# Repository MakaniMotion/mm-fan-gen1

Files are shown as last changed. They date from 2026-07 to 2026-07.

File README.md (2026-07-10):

<p align="center">
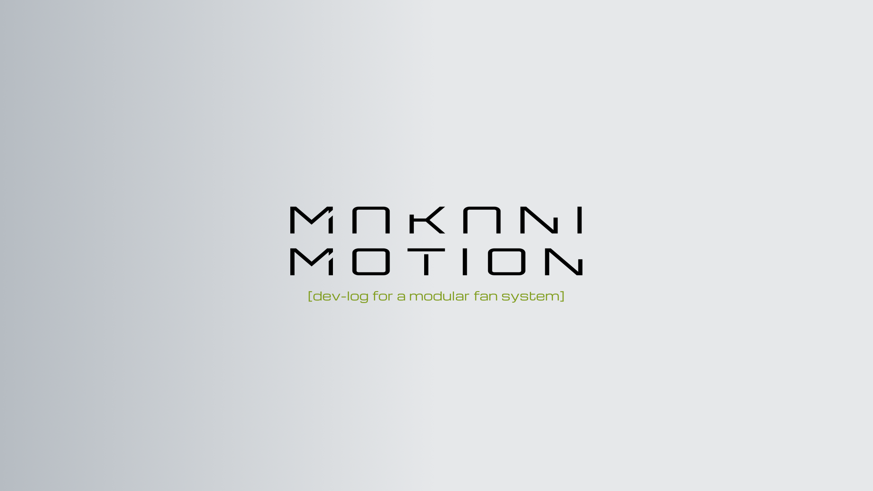
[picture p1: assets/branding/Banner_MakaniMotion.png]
MakaniMotion Banner
  
</p>

# MakaniMotion MM-Fan GEN 1

A modular DIY fan platform.

## Table of Contents

- [Overview](#overview)
- [Motivation](#motivation)
- [Modules](#modules)
  - [MM-BASE](#mm-base)
  - [MM-AIR](#mm-air)
  - [MM-TRI](#mm-tri)
- [System Parts](#system-parts)
- [Build Configurations](#build-configurations)
  - [Table Version](#table-version)
  - [Stand Version](#stand-version)
- [Project Status](#project-status)
- [License / Usage](#license--usage)

## Overview

MakaniMotion MM-Fan GEN 1 is a modular DIY fan platform built around interchangeable modules.

The system can be assembled in different configurations and combines PC fan hardware, 3D-printed mechanical parts and a simple control interface.

## Motivation

The goal of this project is to develop a fan system that is quiet, modular, energy-efficient and visually aesthetic.

The design is based on high-performance PC / gaming fans. These fans are developed in a highly competitive market and are therefore typically optimized for low noise, low power consumption and high airflow.

The main challenge of MakaniMotion MM-Fan GEN 1 is to adapt these properties to the use case of a room fan. Instead of only moving air through a PC case, radiator or filter, the system is designed to create a more focused and usable airflow for indoor use.

## Modules

MakaniMotion MM-Fan GEN 1 is built around three main modules. Each module has a dedicated function and can be combined with the other modules depending on the desired build configuration.

### MM-BASE

<p align="left">
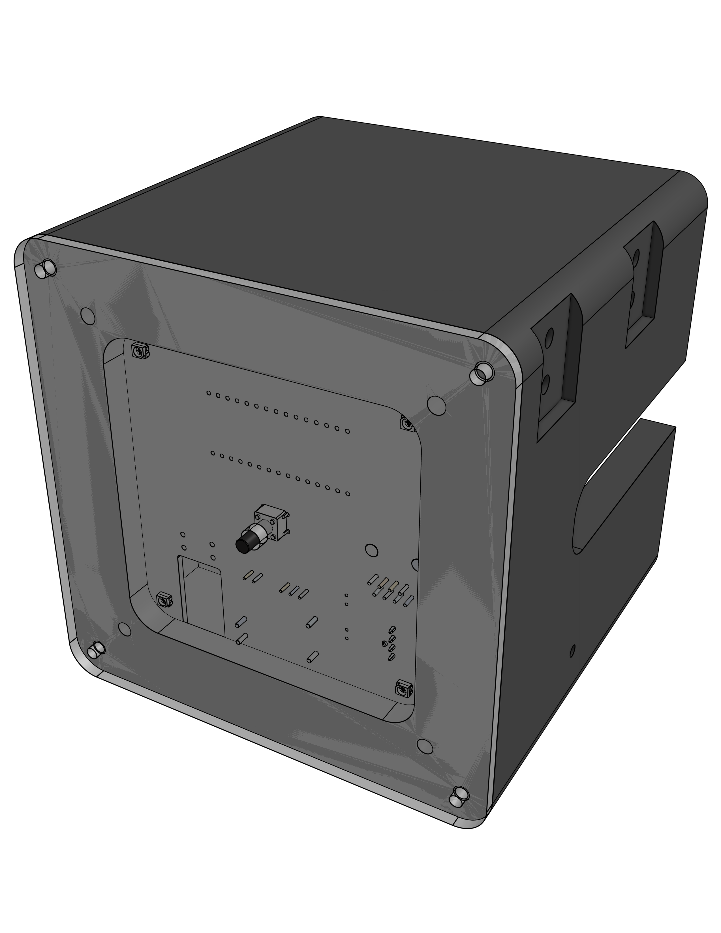
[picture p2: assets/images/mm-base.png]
MM-BASE Module
  
</p>

**MM-BASE** is the base and control module of the system.

It provides the main electrical control interface, power distribution and user interface for the fan setup. The GEN 1 main PCBA uses an Arduino Nano to keep the project easy to reproduce.

MM-BASE is intended to be powered from a suitable 5 V USB power bank. The enclosure is designed to fit smaller power banks inside the module, allowing the system to be used as a battery-powered device without using a custom battery pack.

In the current GEN 1 prototype, MM-BASE may not work directly with all USB chargers. A power source with an active/default 5 V output is required.

| Item | Description |
|---|---|
| Module name | MM-BASE |
| Main PCBA | mm-main-pcba-gen1-reva |
| Controller | Arduino Nano |
| Power input | 5 V |
| Recommended power source | Suitable USB power bank |
| Power source requirement | Active/default 5 V output |
| Power bank integration | Enclosure space for smaller power banks |
| Power stage | 10 W DC/DC converter |
| Supported MM-AIR modules | Up to 5 MM-AIR modules in the current setup |
| HMI | One push button for PWM level selection |
| Status indication | Four RGB LEDs indicate the selected PWM level using different colors |
| Design goal | Easy to build, easy to understand and suitable for DIY reproduction |

### MM-AIR

<p align="left">
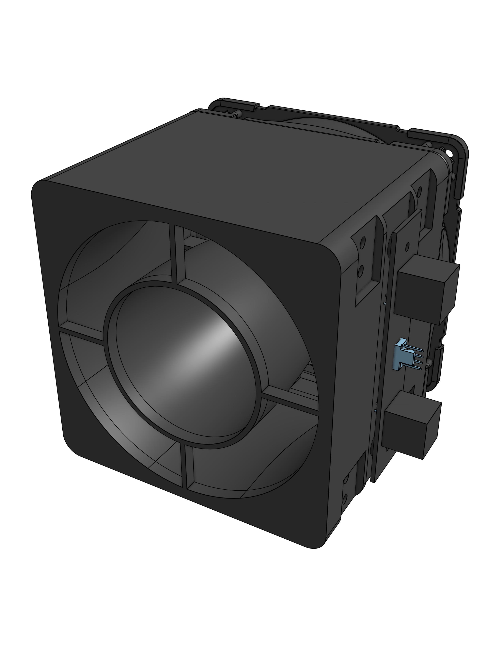
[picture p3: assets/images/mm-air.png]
MM-AIR Module
  
</p>

**MM-AIR** is the fan / airflow module of the system.

It uses a Noctua NF-A12x25 PWM 120 mm fan, selected for its low noise level, low power consumption and high airflow performance.

The fan is mounted to a 3D-printed shroud that reduces the outlet cross-section. This helps increase air velocity and creates a more focused airflow for use as a room fan.

An interface PCB is mounted on the side of the module. The **mm-interface-pcba-gen1-reva** connects MM-AIR to the daisy-chain system and provides two RJ45 sockets and one PC fan header.

| Item | Description |
|---|---|
| Module name | MM-AIR |
| Fan | Noctua NF-A12x25 PWM |
| Fan size | 120 mm |
| Fan control | PWM |
| Interface PCBA | mm-interface-pcba-gen1-reva |
| System connectors | 2 × RJ45 sockets for daisy-chain connection |
| Fan connector | 1 × PC fan header |
| Mechanical design | 3D-printed shroud |
| Airflow concept | Reduced outlet cross-section to increase air velocity |
| Design goal | Quiet operation with focused, usable airflow |

### MM-TRI

<p align="left">
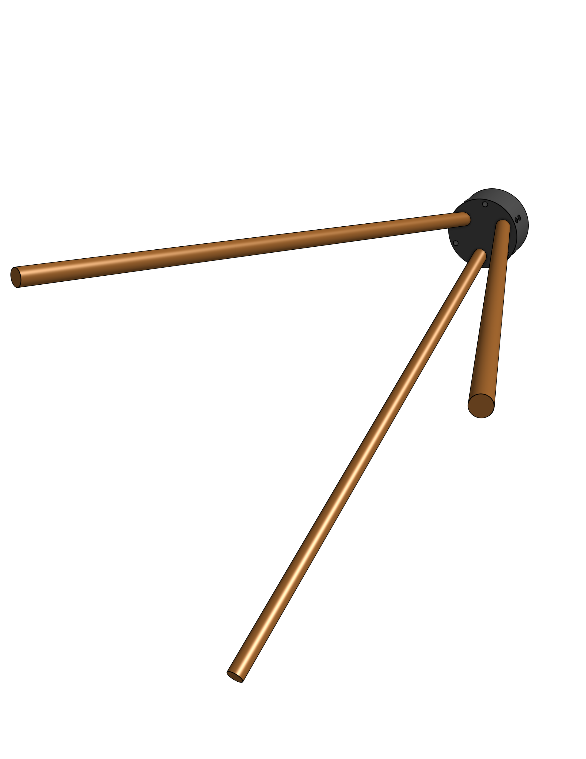
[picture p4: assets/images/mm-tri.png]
MM-TRI Module
  
</p>

**MM-TRI** is the tripod module for the free-standing build configuration.

It provides a simple and stable three-leg support structure for the system.

The three-leg design avoids mechanical overconstraint and helps the fan stand securely on uneven surfaces.

The module is intentionally kept simple and minimal while still maintaining an elegant appearance. In the current version, MM-TRI is attached to MM-BASE using three screws, making it easy to switch between the table version and the free-standing configuration.

| Item | Description |
|---|---|
| Module name | MM-TRI |
| Module type | Tripod module |
| Mechanical concept | Three-leg support structure to avoid mechanical overconstraint |
| Mounting interface | Attached to MM-BASE using a single screw |
| Required for | Stand version |
| Design goal | Simple, stable and elegant free-standing support |

## System Parts

The system also includes physical parts that belong to the overall GEN 1 system but are not assigned to a single module.

- **MM-CONNECT** – mechanical connection element
- **Connection Cables** – The connection cables are based on RJ45, but they are not used for Ethernet networking. They are repurposed as system connection cables for power and signals between modules.

## Build Configurations

MakaniMotion MM-Fan GEN 1 can typically be assembled in two main configurations:

### Table Version

The table version is designed to be placed on a desk or similar surface.

<p align="left">
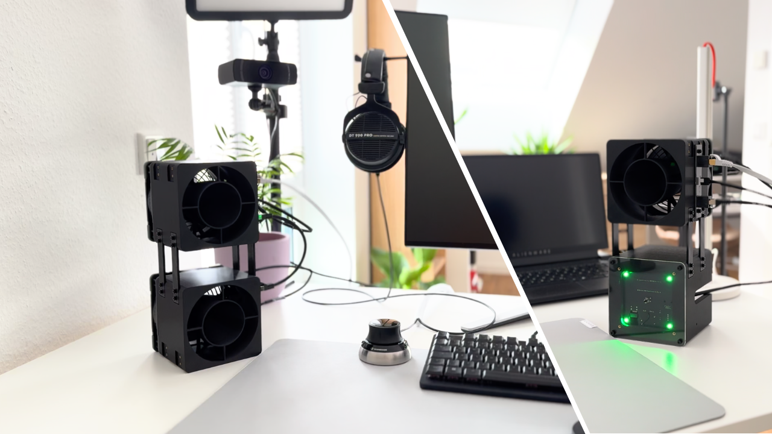
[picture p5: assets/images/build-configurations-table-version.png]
MakaniMotion Fan GEN 1 Table Version
  
</p>

In this configuration, the **MM-TRI** tripod module is not required.

Because the modules are connected by cables, the physical layout can be adapted to different use cases and desk setups.

### Stand Version

The stand version is designed as a free-standing fan setup.

<p align="left">
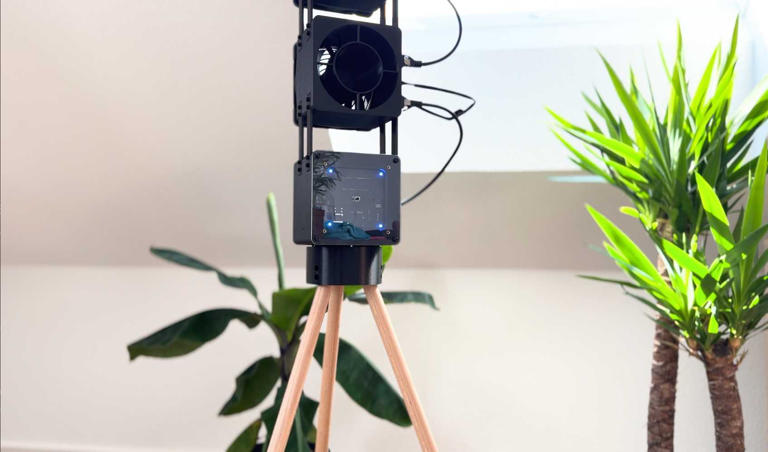
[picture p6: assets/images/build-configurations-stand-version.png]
MakaniMotion Fan GEN 1 Stand Version
  
</p>

In this configuration, the **MM-TRI** tripod module is required.

## Project Status

Prototype / work in progress.

This repository contains the first product generation:

```text
MakaniMotion MM-Fan GEN 1
```

Module revisions within this generation are tracked separately, for example:

```text
MM-Base GEN 1 Rev A
MM-Air GEN 1 Rev A
MM-TRI GEN 1 Rev A
```

This project is a DIY development project and is not a certified consumer product.

No CE declaration, conformity assessment or safety certification.

Anyone building hardware based on this project does so at their own risk and is responsible for safe assembly and operation.

## License / Usage

This project is source-available for private and non-commercial use only.

Private individuals may view, download, build and modify the project files for personal use.

Non-commercial sharing or uploading of modified project files is allowed if MakaniMotion is clearly credited as the original source and this license remains included.

Commercial use is not permitted. This includes use by companies, commercial organizations, paid services, commercial product development, manufacturing for commercial purposes, or distributing physical devices, kits, parts or assemblies based on this project.

For details, see [`LICENSE.md`](LICENSE.md).

© MakaniMotion. All rights reserved unless otherwise stated.

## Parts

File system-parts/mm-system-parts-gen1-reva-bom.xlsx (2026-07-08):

MakaniMotion MM-SYSTEM-PARTS
Project | MakaniMotion MM-Fan GEN 1
Module | MM-SYSTEM-PARTS
Revision | Rev A
Item | Component | Sub component | Description | Qty | Source | Supplier / Manufacturer | Part No. / File Ref. | Link
1 | Network Cable S/FTP PIMF Cat 7 0.25 m Black Patch Cable Gigabit Ethernet LAN DSL CAT7 Cable |  | A cable is required for each MM-AIR module used | dependet | Buy |  |  | https://www.amazon.de/gp/product/B08HDJLJ9J/ref=ox_sc_act_title_1?th=1&language=en_GB
2 | Network Cable S/FTP PIMF Cat 7 0.50 m Black Patch Cable Gigabit Ethernet LAN DSL CAT7 Cable |  | A slightly longer cable is required for the connection from MM-BASE to MM-AIR. | 1 | Buy |  |  | https://www.amazon.de/gp/product/B08HDG8GV2/ref=ox_sc_act_title_1?th=1&language=en_GB
3 | Screw M3 x 8mm |  | 16 Screws are required for each MM-AIR module used | dependet | Buy
4 | M3 Washers |  | 16 Washers are required for each MM-AIR module used | dependet | Buy
5 | mm-connect-gen1-reva.stl |  | 4 are required for each MM-AIR module used | dependet | print

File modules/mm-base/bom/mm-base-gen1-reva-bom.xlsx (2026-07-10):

MakaniMotion MM-BASE
Project | MakaniMotion MM-Fan GEN 1
Module | MM-BASE
Revision | Rev A
Item | Component | Sub component | Description | Qty | Source | Supplier / Manufacturer | Part No. / File Ref. | Link
1 | mm-main-pcba-gen1-reva |  |  | 1 | KiCad
1001 |  | PCB | Gerber Files | 1 | Buy
1002 |  | DC/DC Converters - Through Hole 5Vin 5Vout 0-400mA 2W SIP Unreg Iso |  | 1 | Buy | MEAN WELL | SPUN02L-05 | https://www.mouser.de/ProductDetail/MEAN-WELL/SPUN02L-05
1003 |  | DC/DC Converters - Through Hole 4.7-9Vin 12Vout 833mA DIP Iso Reg |  | 1 | Buy | MEAN WELL | SKM10E-12 | https://www.mouser.de/ProductDetail/MEAN-WELL/SKM10E-12
1004 |  | Multi-Colour LEDs WL-SFTW SMT full-color TOP LED waterclear |  | 4 | Buy | Wurth Elektronik | 150141M173100 | https://www.mouser.de/ProductDetail/Wurth-Elektronik/150141M173100?qs=2kOmHSv6VfT%2Fmnpysgc7Ng%3D%3D
1005 |  | Short-stroke key 6x6 mm, height: 12.5 mm, 12 V, vert. |  | 1 | Buy | FREI | JTP-1130D | https://www.reichelt.com/de/en/shop/product/short-stroke_key_6x6_mm_height_12_5_mm_12_v_vert_-27894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
1006 |  | Arduino Nano |  | 1 | Buy | Arduino | A000005 | https://store.arduino.cc/products/arduino-nano
1007 |  | Aluminium Electrolytic Capacitors - Radial Leaded WCAP-ATG8 100uF 35V 20% Radial |  | 2 | Buy | Wurth Elektronik | 860010573007 | https://www.mouser.de/ProductDetail/Wurth-Elektronik/860010573007
1008 |  | Bipolar Transistors - BJT LO V NPN TRANSISTOR 40V 4.0A |  | 6 | Buy | onsemi | NSS40201LT1G | https://www.mouser.de/ProductDetail/onsemi/NSS40201LT1G?qs=JZRcihQa5buDxAwNVotiBw%3D%3D
1009 |  | USB Connectors USB Type C Receptacle Surface Mount Single Row 6Pin |  | 1 | Buy | Amphenol FCI | 10164359-00011LF | https://www.mouser.de/ProductDetail/Amphenol-FCI/10164359-00011LF?qs=MyNHzdoqoQLpQ%2FmSqA1%252BtQ%3D%3D
1010 |  | Modular Connectors / Ethernet Connectors WR-MJ_8P8C_THT_Vertical |  | 1 | Buy | Wurth Elektronik | 615008160321 | https://www.mouser.de/ProductDetail/Wurth-Elektronik/615008160321?qs=OlC7AqGiEDmnhkTBXznxsQ%3D%3D
1011 |  | female connector 2,54mm, 1x16, separable, gold plated |  | 2 | Buy | FISCHER ELEKTRONIK | BL1.16 G | https://www.reichelt.com/de/en/shop/product/female_connector_2_54mm_1x16_separable_gold_plated-283786
1012 |  | Resistor 3KOhm 1206 |  | 3 | Buy
1013 |  | Resistor 90Ohm 1206 |  | 8 | Buy
1014 |  | Resistor 150Ohm 1206 |  | 4 | Buy
2 | mm-base-gen1-enclosure-cover-reva.step |  |  | 1 | Buy or print
3 | M3 x 8mm |  | mm-base-gen1-enclosure-cover-reva.step mounting | 4 | Buy
4 | M3 Washers |  | mm-base-gen1-enclosure-cover-reva.step mounting | 4 | Buy
5 | M3 x 6mm |  | PCB mounting | 4 | Buy
6 | M3 thread insert |  |  | 22 | Buy | ruthex | GE-M3x57-001 | https://www.ruthex.de/en/products/ruthex-gewindeeinsatz-m3-100-stuck-rx-m3x5-7-messing-gewindebuchsen
7 | mm-base-gen1-enclosure-reva.stl |  |  | 1 | print
8 | USB C 180 Degree Angled Adapter |  | Depending on the USB connector, this adapter is necessary | 1 | buy |  |  | https://www.amazon.de/-/en/dp/B0BLMTGX8H?ref_=ppx_hzsearch_conn_dt_b_fed_asin_title_8&th=1
9 | USB C Cable 0.5m |  | Short cable for connecting a power bank | 1 | buy

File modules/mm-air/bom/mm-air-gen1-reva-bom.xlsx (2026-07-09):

MakaniMotion MM-AIR
Project | MakaniMotion MM-Fan GEN 1
Module | MM-AIR
Revision | Rev A
Item | Component | Sub component | Description | Qty | Source | Supplier / Manufacturer | Part No. / File Ref. | Link
1 | mm-interface-pcba-gen1-reva |  |  | 1 | KiCad
1001 |  | PCB | Gerber Files | 1 | Buy
1002 |  | Modular Connectors / Ethernet Connectors WR-MJ_8P8C_THT_Vertical |  | 2 | Buy | Wurth Elektronik | 615008160321 | https://www.mouser.de/ProductDetail/Wurth-Elektronik/615008160321?qs=OlC7AqGiEDmnhkTBXznxsQ%3D%3D
1003 |  | Headers & Wire Housings 4P VERT HDR W/FL |  | 1 | Buy | Molex | 47053-1000 | https://www.mouser.de/ProductDetail/Molex/47053-1000?qs=ph4zPCVRuvqoDX7hrEhxNA%3D%3D
2 | M3 thread insert |  |  | 20 | Buy | ruthex | GE-M3x57-001 | https://www.ruthex.de/en/products/ruthex-gewindeeinsatz-m3-100-stuck-rx-m3x5-7-messing-gewindebuchsen
3 | Screw M3 x 30mm |  | Fan mounting | 4 | Buy
4 | Screw M3 x 6mm |  | mm-interface-pcba-gen1-reva mounting | 2 | Buy
5 | M3 Washers |  | Mounting Hardware | 4 | Buy
6 | NF-A12x25 PWM chromax.black.swap |  | Fan | 1 | Buy | Noctua | NF-A12x25 PWM chromax.black.swap
7 | NA-FG1-12 Sx2 |  | Fan grills | 1 | Buy | Noctua | NA-FG1-12 Sx2
8 | mm-air-shroud-gen1-reva |  |  | 1 | Print

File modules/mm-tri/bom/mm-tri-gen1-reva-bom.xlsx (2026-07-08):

MakaniMotion MM-TRI
Project | MakaniMotion MM-Fan GEN 1
Module | MM-TRI
Revision | Rev A
Item | Component | Sub component | Description | Qty | Source | Supplier / Manufacturer | Part No. / File Ref. | Link
1 | mm-tri-gen1-enclosure-reva.stl |  |  | 1 | print
2 | mm-tri-gen1-leg-reva.step |  | 20mm x 750mm | 3 | buy
3 | M3 x 8mm |  | MM-BASE Mounting | 3 | buy
4 | M3 Washers |  | MM-BASE Mounting | 3 | buy
5 | 3 × 10 mm wood screw |  | mm-tri-gen1-leg-reva Mounting | 3 | buy

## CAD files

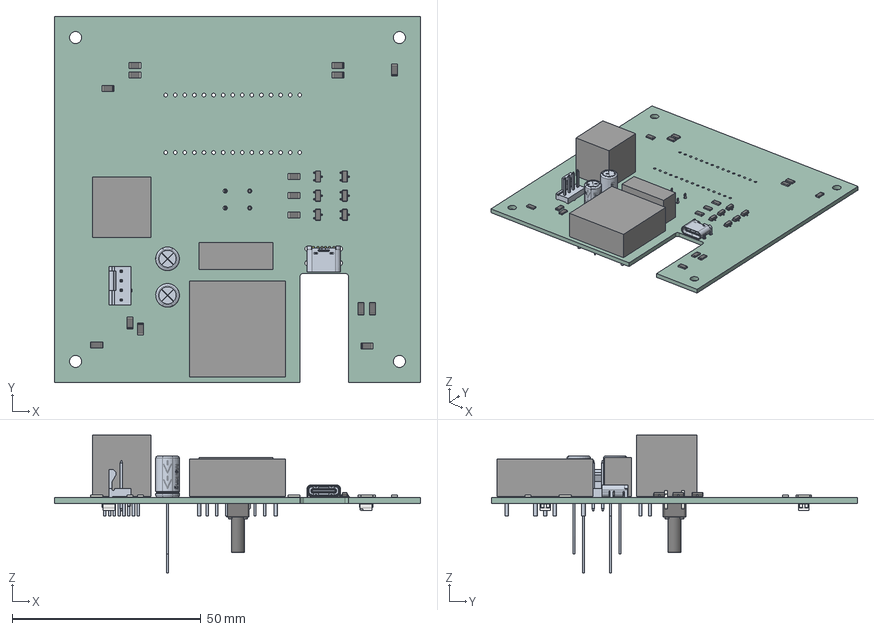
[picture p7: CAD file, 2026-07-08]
modules/mm-base/electronics/mm-main-pcba-gen1-reva/exports/mm-main-pcba-gen1-reva.step
97.0 x 97.0 x 36.5 mm
R_1206_3216Metric x 15
10164359-00011LF
ASSEMBLY x 3
SOT-23-3 x 6
CP_Wurth_WCAP-ATG8-P2.5D6.3L11 x 2
150141M173100 x 4
SW_PUSH_6mm_h13mm
DIYFAN_V1_PCB

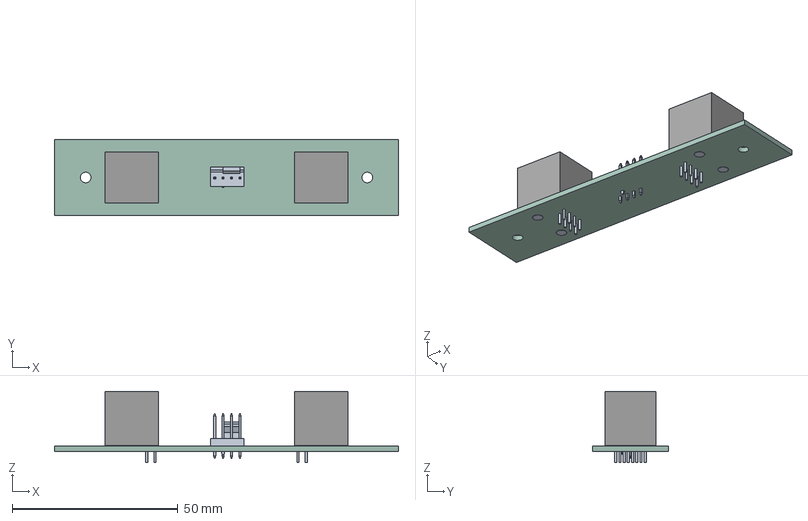
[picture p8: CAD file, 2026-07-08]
modules/mm-air/electronics/mm-interface-pcba-gen1-reva/exports/mm-interface-pcba-gen1-reva.step
103.9 x 22.9 x 21.4 mm
ASSEMBLY x 2
DIYFAN _interface_V1_PCB

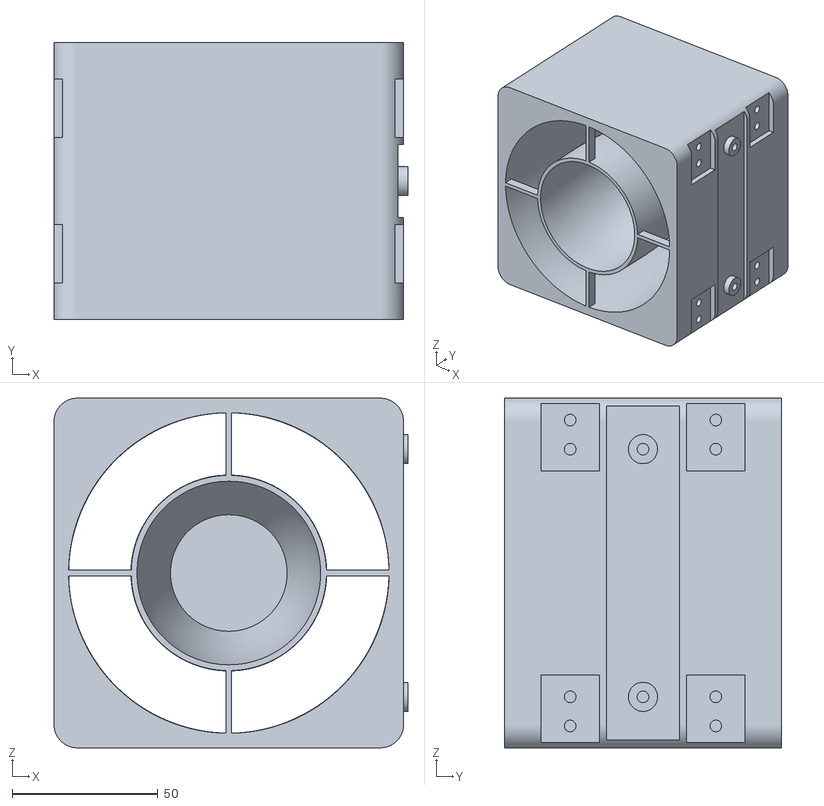
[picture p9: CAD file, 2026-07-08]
modules/mm-air/mechanical/mm-air-shroud-gen1-reva.stl
121.5 x 95.0 x 120.0

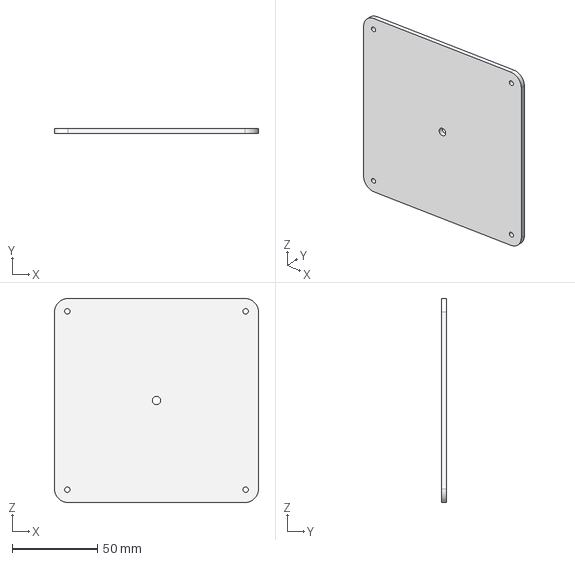
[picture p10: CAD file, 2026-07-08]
modules/mm-base/mechanical/mm-base-gen1-enclosure-cover-reva.step
120.0 x 3.00 x 120.0 mm

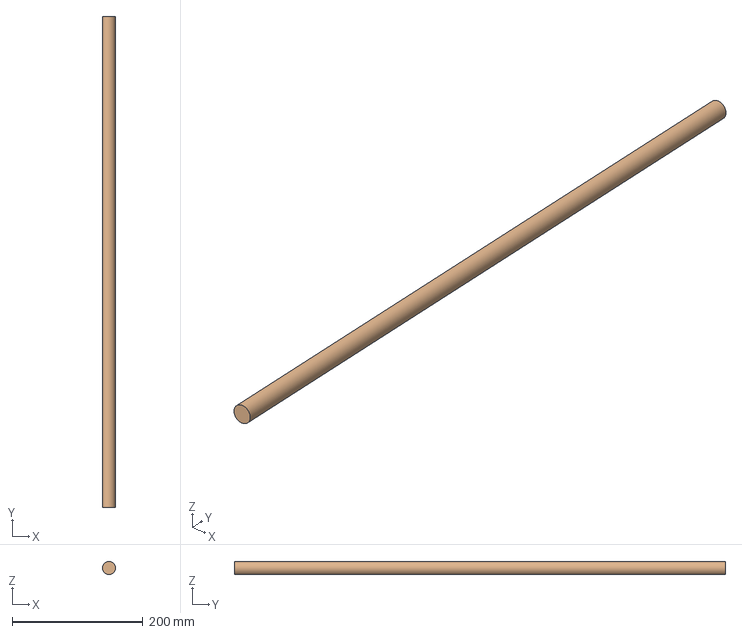
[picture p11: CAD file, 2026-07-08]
modules/mm-tri/mechanical/mm-tri-gen1-leg-reva.step
20.0 x 750.0 x 20.0 mm

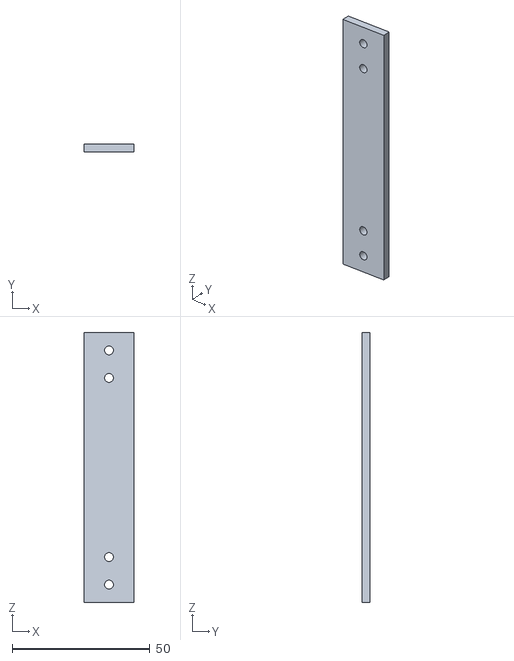
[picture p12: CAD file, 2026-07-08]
system-parts/mm-connect/mm-connect-gen1-reva.stl
18.0 x 3.00 x 98.0

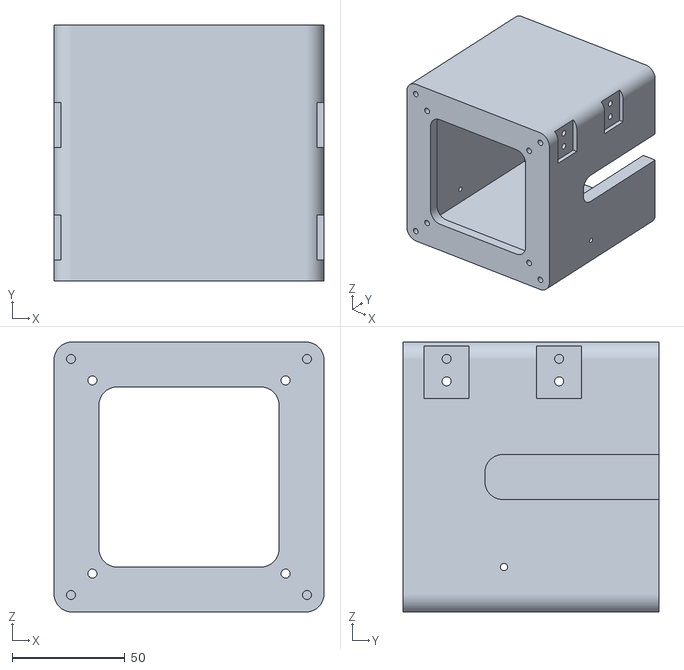
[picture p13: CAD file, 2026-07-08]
modules/mm-base/mechanical/mm-base-gen1-enclosure-reva.stl
120.0 x 114.0 x 120.0

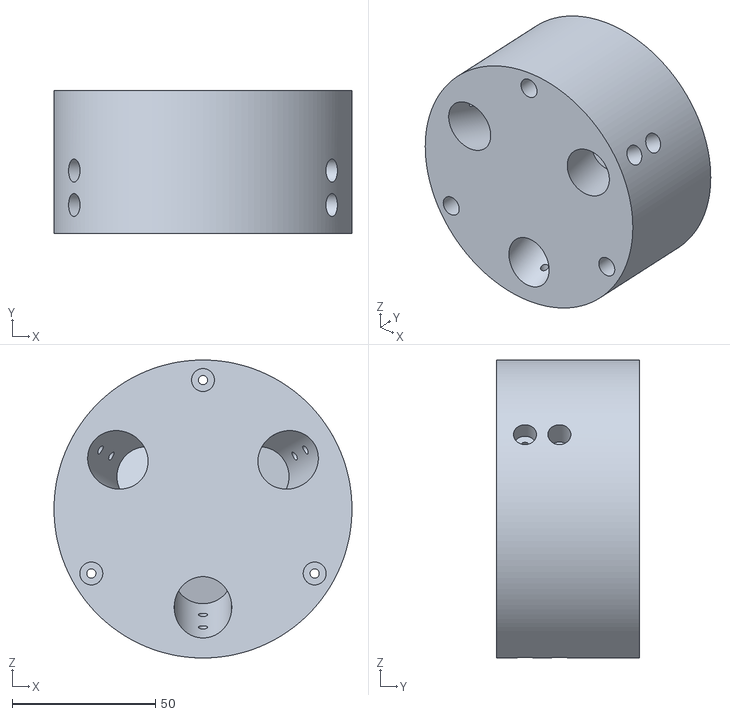
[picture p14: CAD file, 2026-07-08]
modules/mm-tri/mechanical/mm-tri-gen1-enclosure-reva.stl
104.0 x 50.0 x 104.0

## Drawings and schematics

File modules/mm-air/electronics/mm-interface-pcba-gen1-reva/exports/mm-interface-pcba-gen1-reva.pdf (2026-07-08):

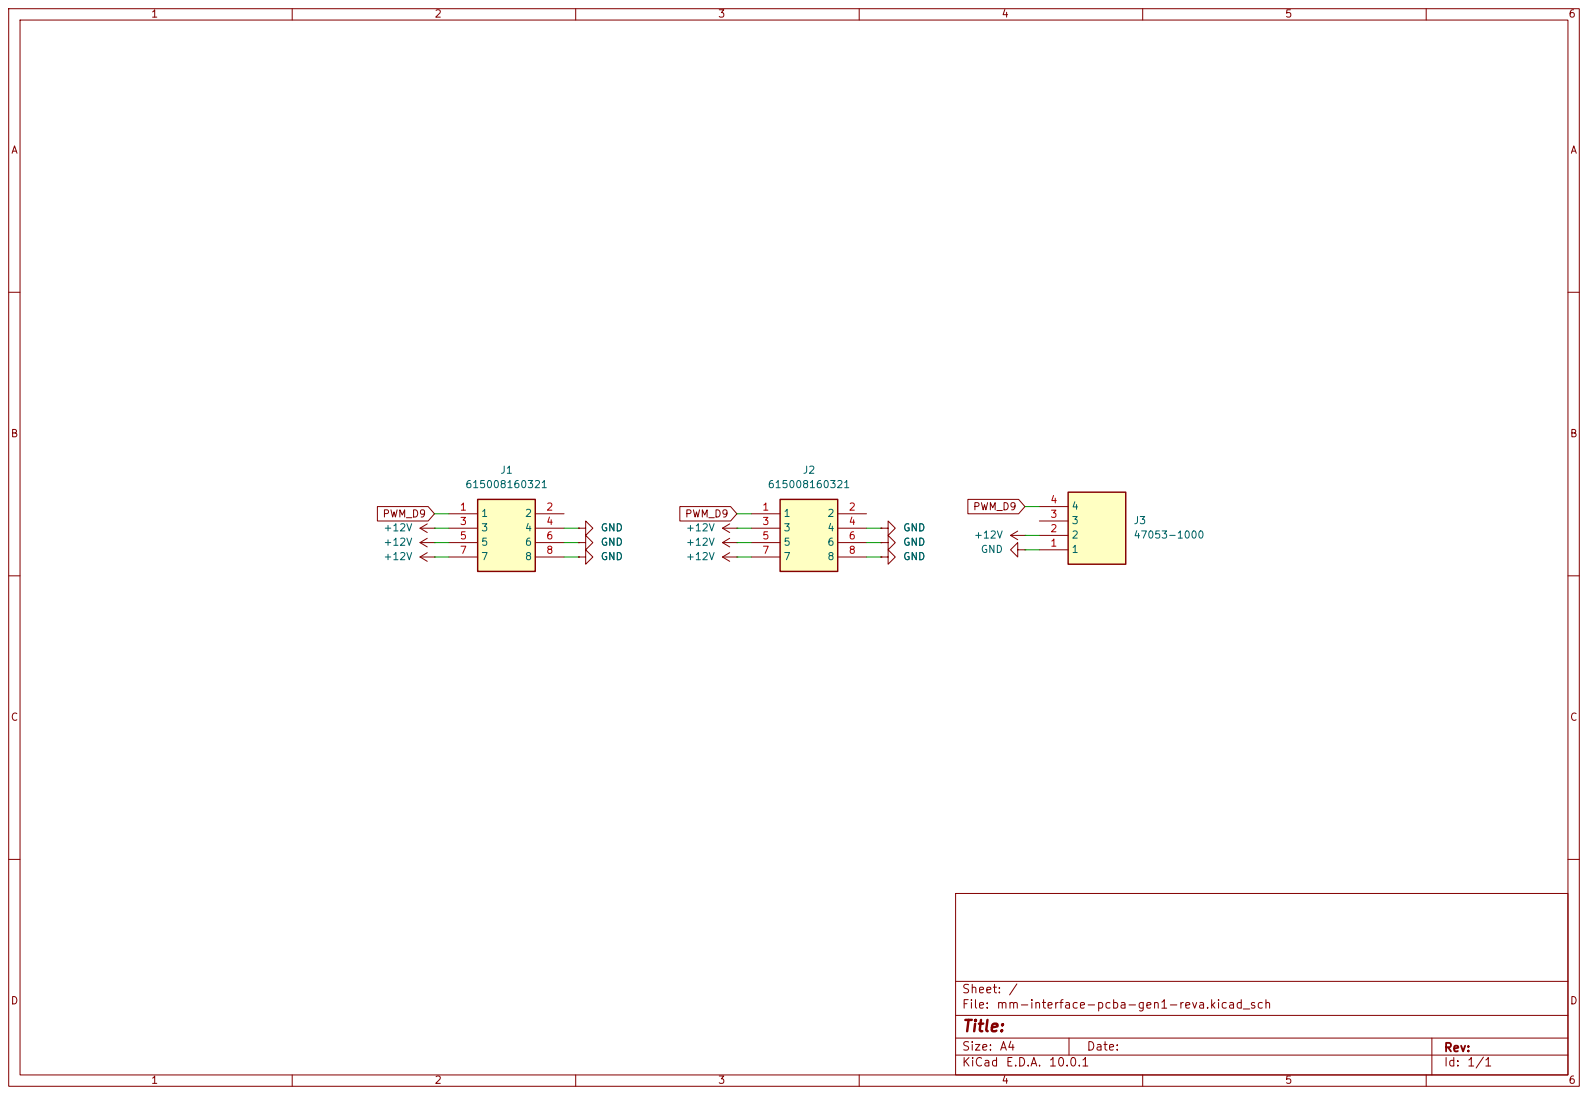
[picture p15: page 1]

File: mm-interface-pcba-gen1-reva.kicad_sch
Title:

Size: A4 | Rev:
KiCad E.D.A. 10.0.1 | Id: 1/1

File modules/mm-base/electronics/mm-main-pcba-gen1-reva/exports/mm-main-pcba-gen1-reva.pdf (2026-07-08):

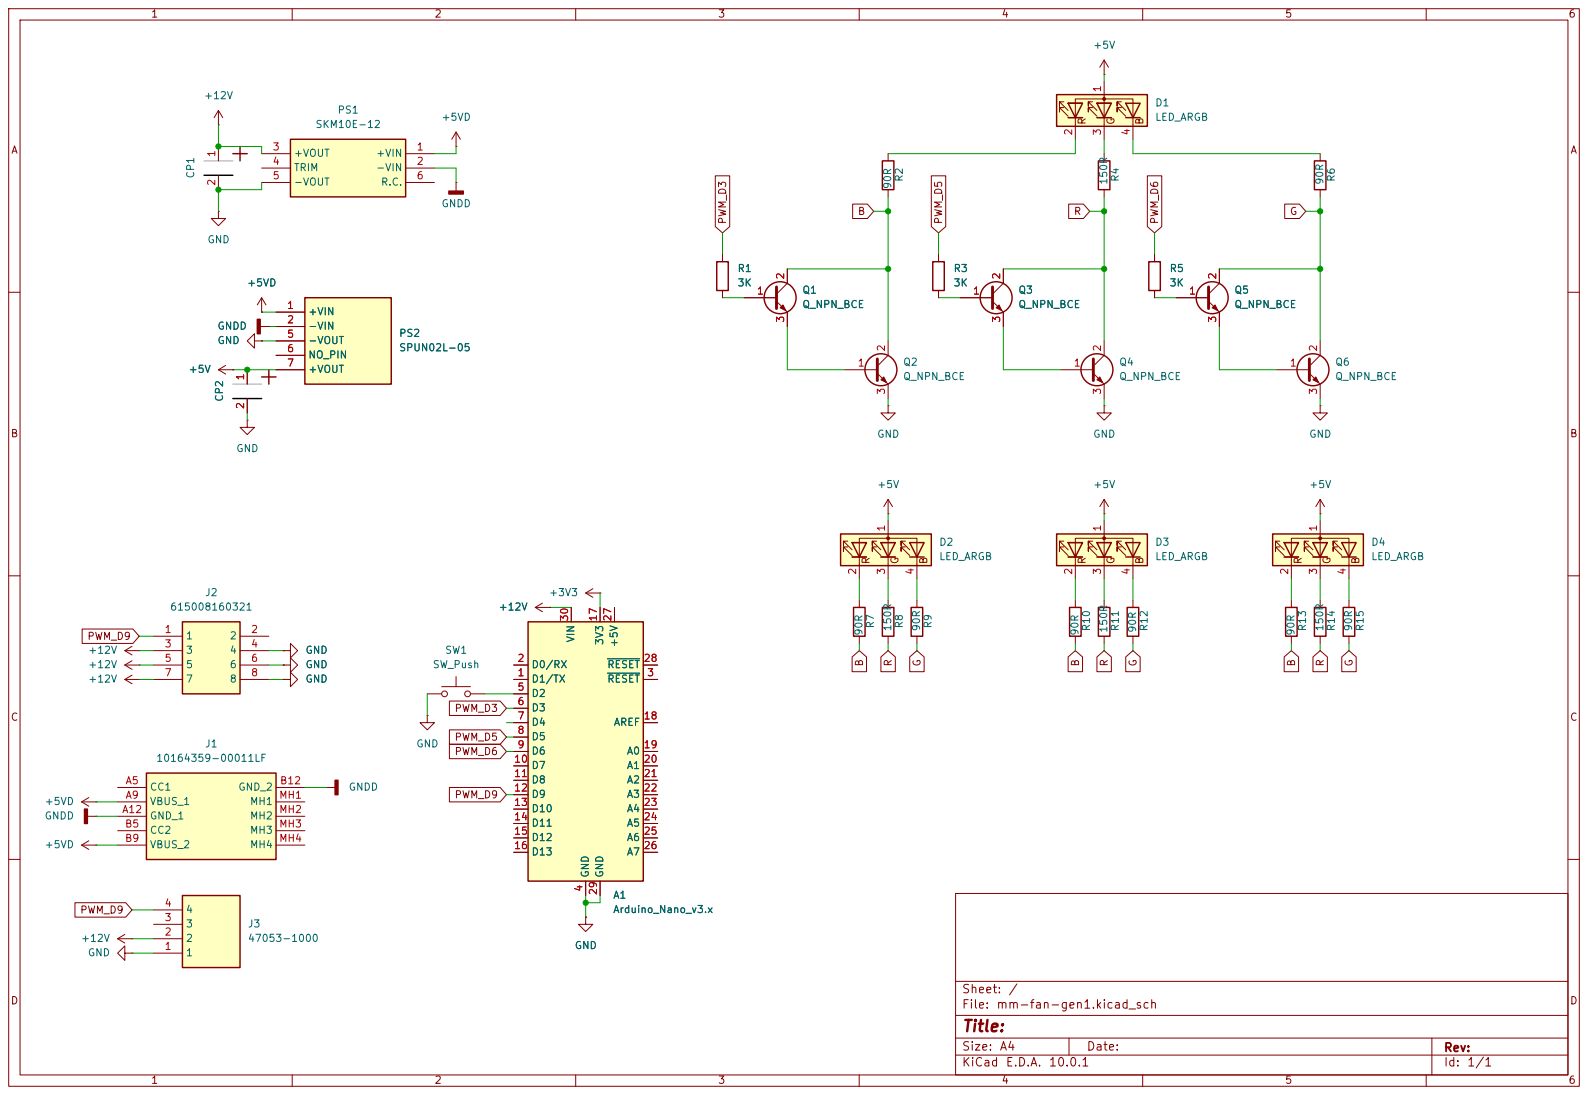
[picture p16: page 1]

Size: A4 | Rev:
KiCad E.D.A. 10.0.1 | Id: 1/1

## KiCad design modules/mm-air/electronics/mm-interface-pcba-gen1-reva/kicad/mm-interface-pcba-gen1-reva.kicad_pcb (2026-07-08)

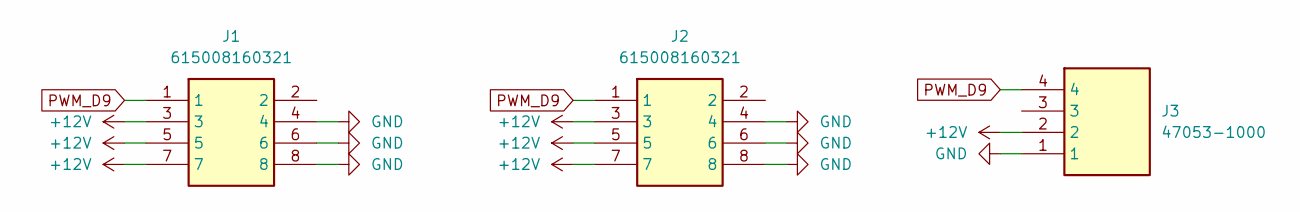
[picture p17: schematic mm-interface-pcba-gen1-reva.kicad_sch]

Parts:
J1, J2: 615008160321; Mouser Part Number 710-615008160321
J3: 47053-1000; 470531000; Mouser Part Number 538-47053-1000

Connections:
+12V: J1.3, J1.5, J1.7, J2.3, J2.5, J2.7, J3.2
GND: J1.4, J1.6, J1.8, J2.4, J2.6, J2.8, J3.1
PWM_D9: J1.1, J2.1, J3.4

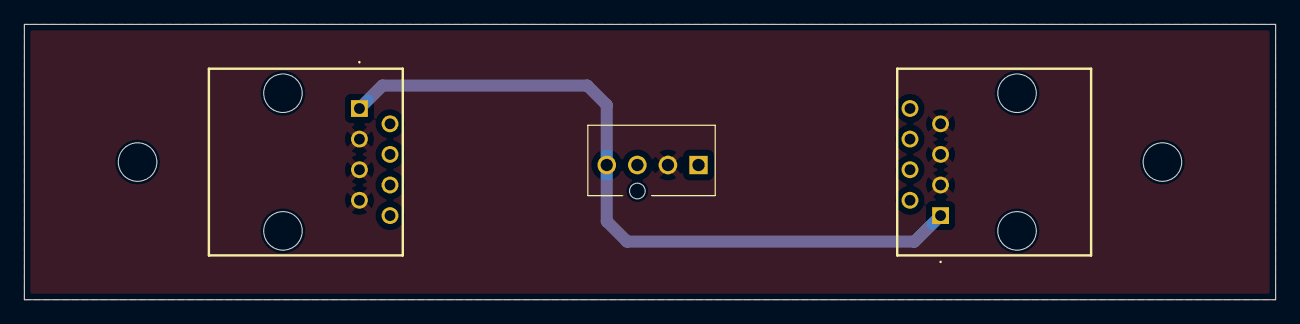
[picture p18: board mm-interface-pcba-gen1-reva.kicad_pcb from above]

Board: 2 copper layers, 103.9 x 22.9 mm, 3 parts (0 on the bottom side), 3 nets.

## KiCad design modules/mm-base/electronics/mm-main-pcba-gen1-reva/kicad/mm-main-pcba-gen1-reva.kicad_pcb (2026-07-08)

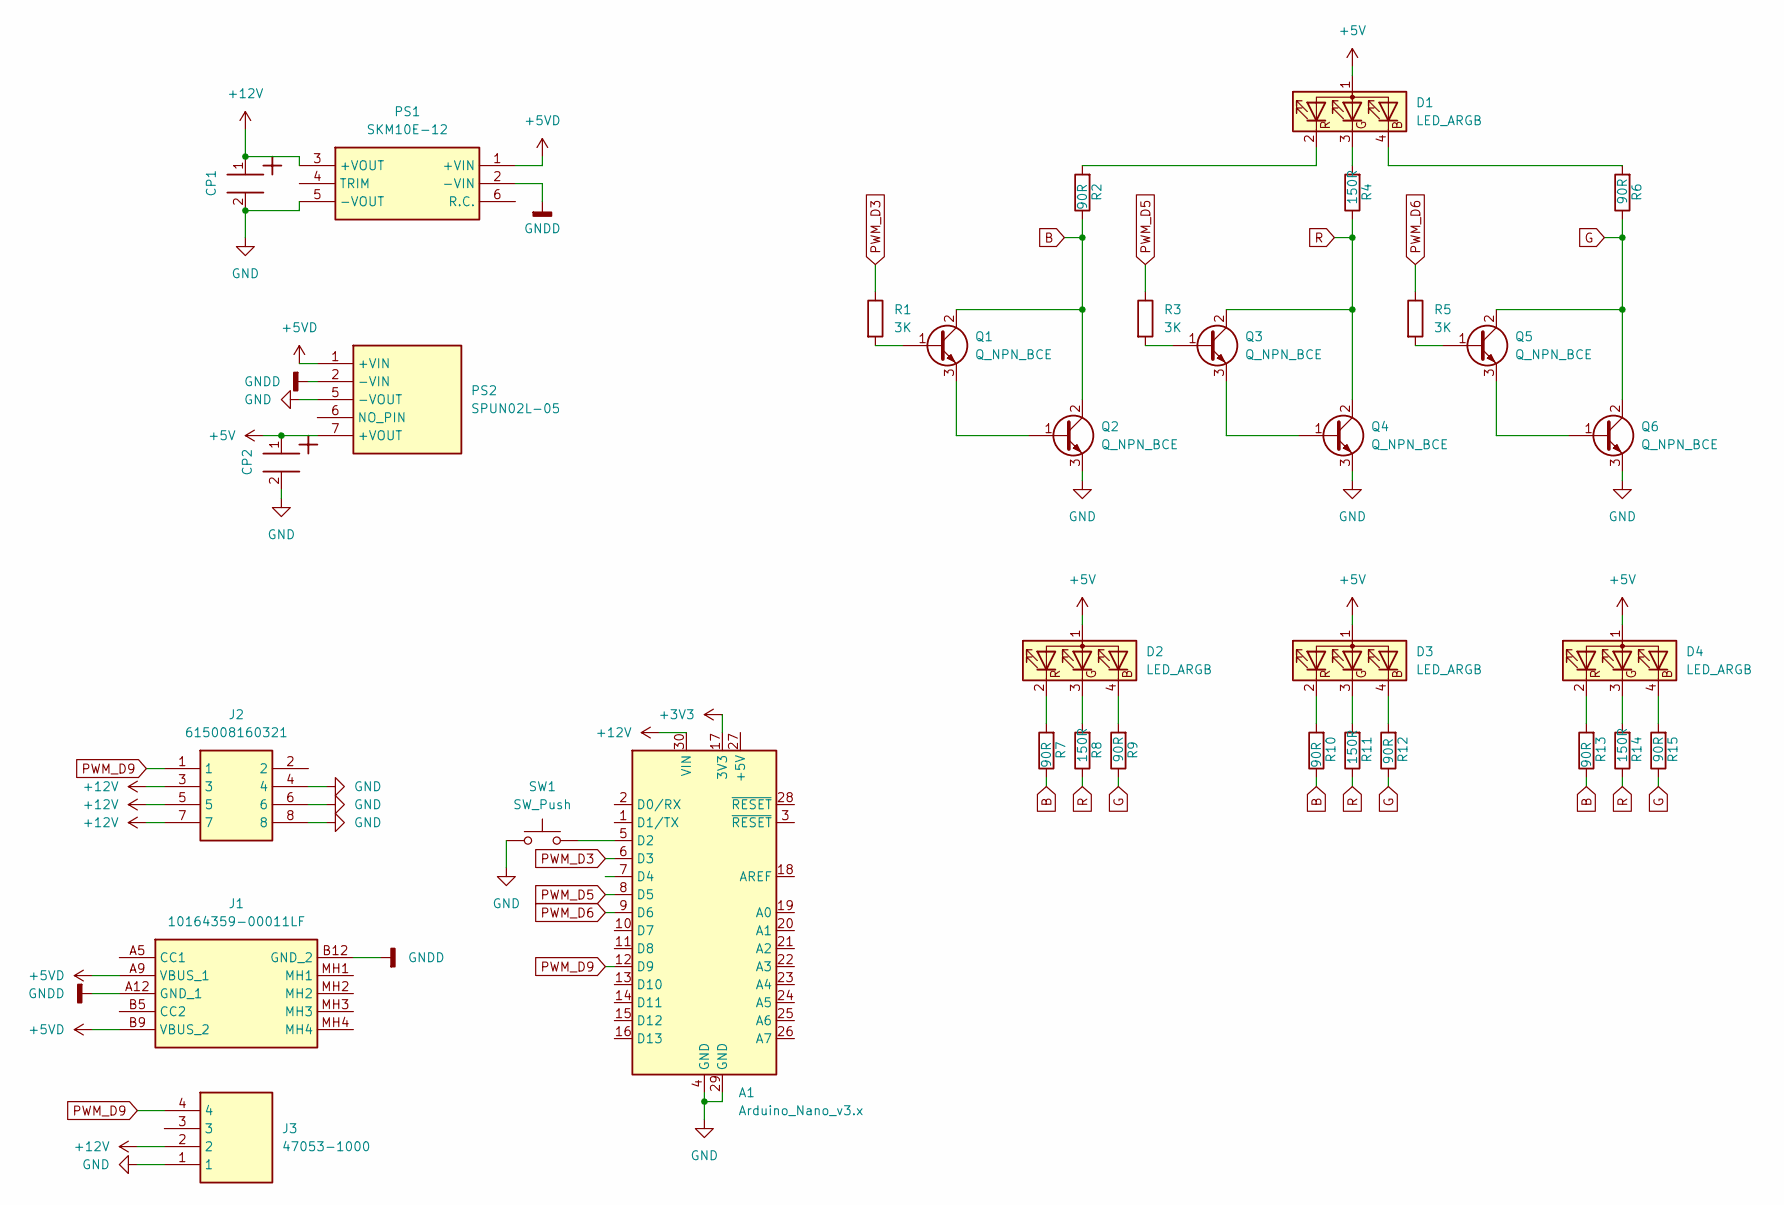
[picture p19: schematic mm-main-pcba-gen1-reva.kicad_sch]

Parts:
A1: Arduino_Nano_v3.x; Arduino_Nano
CP1, CP2: P2.5D6.3L11_860010573007_Modified; CP_Wurth_WCAP-ATG8-P2.5D6.3L11; Part Number 860010573007
D1, D2, D3, D4: LED_ARGB; 150141M173100
J1: 10164359-00011LF; 1016435900011LF_handsoldered; Mouser Part Number 649-10164359-00011LF
J2: 615008160321; Mouser Part Number 710-615008160321
J3: 47053-1000; 470531000; Mouser Part Number 538-47053-1000
PS1: SKM10E-12; SKM10B05; Mouser Part Number 709-SKM10E-12
PS2: SPUN02L-05; SPUN02L05; Mouser Part Number 709-SPUN02L-05
Q1, Q2, Q3, Q4, Q5, Q6: Q_NPN_BCE; SOT-23-3
R1, R3, R5: 3K; R_1206_3216Metric_Pad1.30x1.75mm_HandSolder
R2, R6, R7, R9, R10, R12, R13, R15: 90R; R_1206_3216Metric_Pad1.30x1.75mm_HandSolder
R4, R8, R11, R14: 150R; R_1206_3216Metric_Pad1.30x1.75mm_HandSolder
SW1: SW_Push; SW_PUSH_6mm_H13mm

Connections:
+3V3: A1.17 (3V3)
+5V: CP2.1, D1.1 (A), D2.1 (A), D3.1 (A), D4.1 (A), PS2.7 (+VOUT)
+5VD: J1.A9 (VBUS_1), J1.B9 (VBUS_2), PS1.1 (+VIN), PS2.1 (+VIN)
+12V: A1.30 (VIN), CP1.1, J2.3, J2.5, J2.7, J3.2, PS1.3 (+VOUT)
B: Q1.2 (C), Q2.2 (C), R2.1, R7.1, R10.1, R13.1
G: Q5.2 (C), Q6.2 (C), R6.1, R9.1, R12.1, R15.1
GND: A1.4 (GND), A1.29 (GND), CP1.2, CP2.2, J2.4, J2.6, J2.8, J3.1, PS1.5 (-VOUT), PS2.5 (-VOUT), Q2.3 (E), Q4.3 (E), Q6.3 (E), SW1.1
GNDD: J1.A12 (GND_1), J1.B12 (GND_2), PS1.2 (-VIN), PS2.2 (-VIN)
unnamed: A1.5 (D2), SW1.2
unnamed: D1.4 (BK), R6.2
unnamed: D1.3 (GK), R4.2
unnamed: D1.2 (RK), R2.2
unnamed: D2.4 (BK), R9.2
unnamed: D2.3 (GK), R8.2
unnamed: D2.2 (RK), R7.2
unnamed: D3.4 (BK), R12.2
unnamed: D3.3 (GK), R11.2
unnamed: D3.2 (RK), R10.2
unnamed: D4.4 (BK), R15.2
unnamed: D4.3 (GK), R14.2
unnamed: D4.2 (RK), R13.2
unnamed: Q1.1 (B), R1.2
unnamed: Q1.3 (E), Q2.1 (B)
unnamed: Q3.1 (B), R3.2
unnamed: Q3.3 (E), Q4.1 (B)
unnamed: Q5.1 (B), R5.2
unnamed: Q5.3 (E), Q6.1 (B)
PWM_D3: A1.6 (D3), R1.1
PWM_D5: A1.8 (D5), R3.1
PWM_D6: A1.9 (D6), R5.1
PWM_D9: A1.12 (D9), J2.1, J3.4
R: Q3.2 (C), Q4.2 (C), R4.1, R8.1, R11.1, R14.1

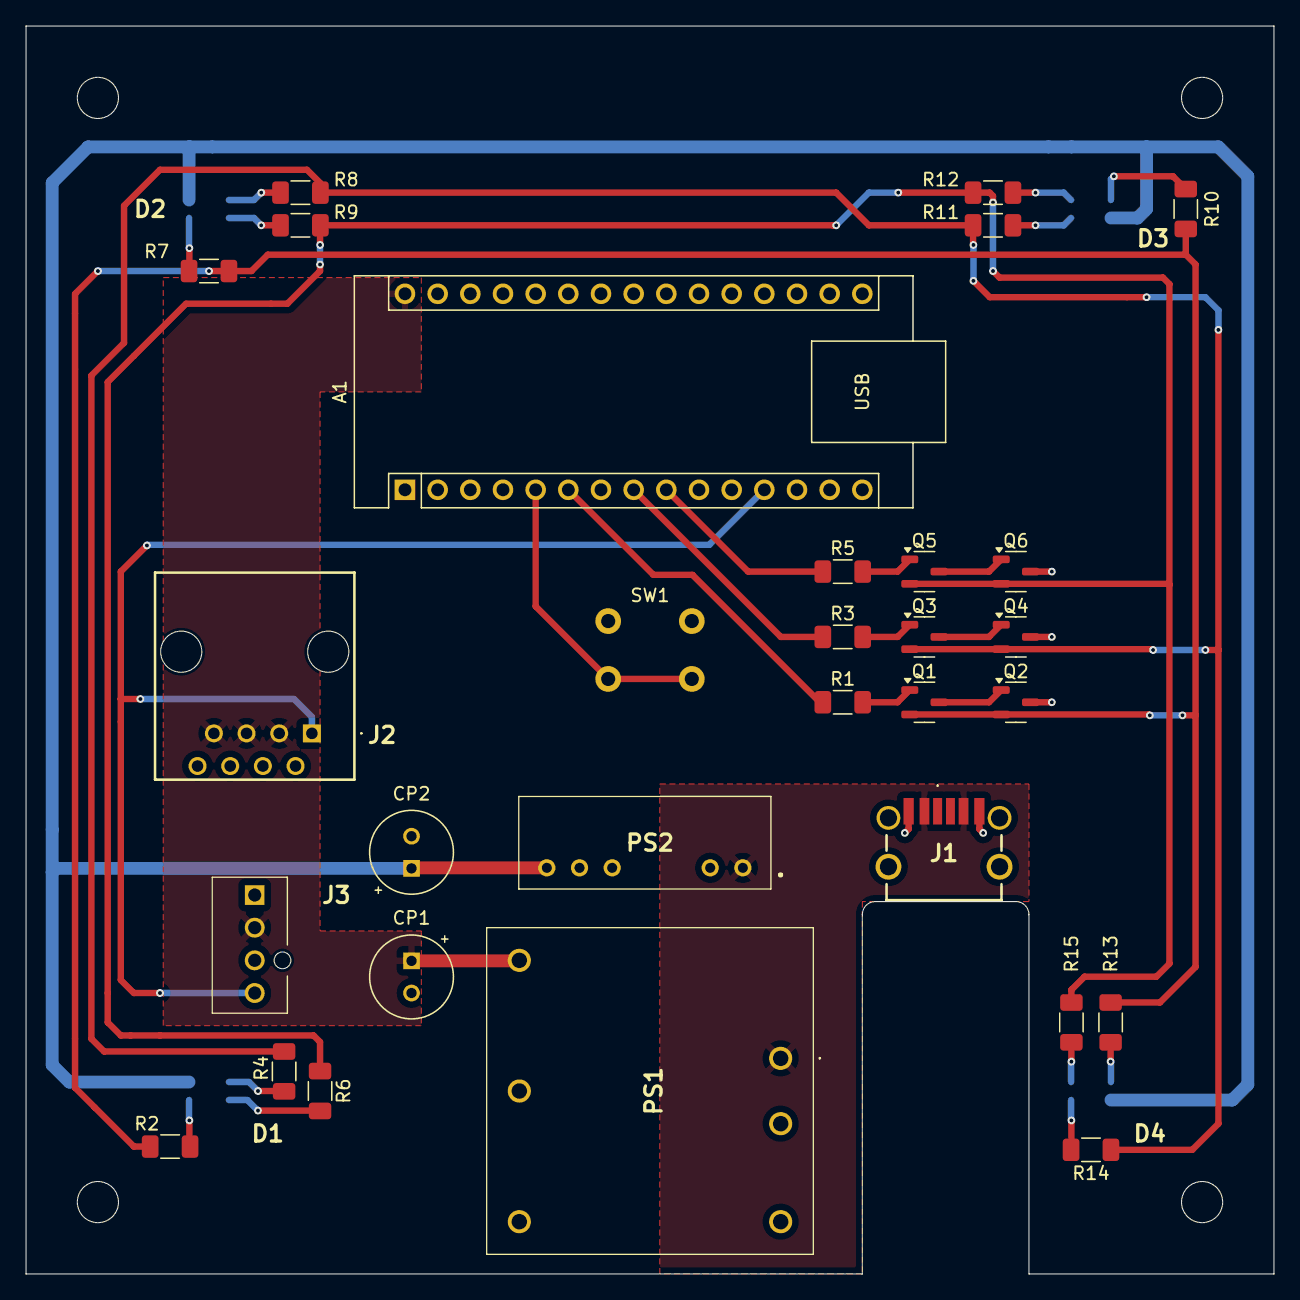
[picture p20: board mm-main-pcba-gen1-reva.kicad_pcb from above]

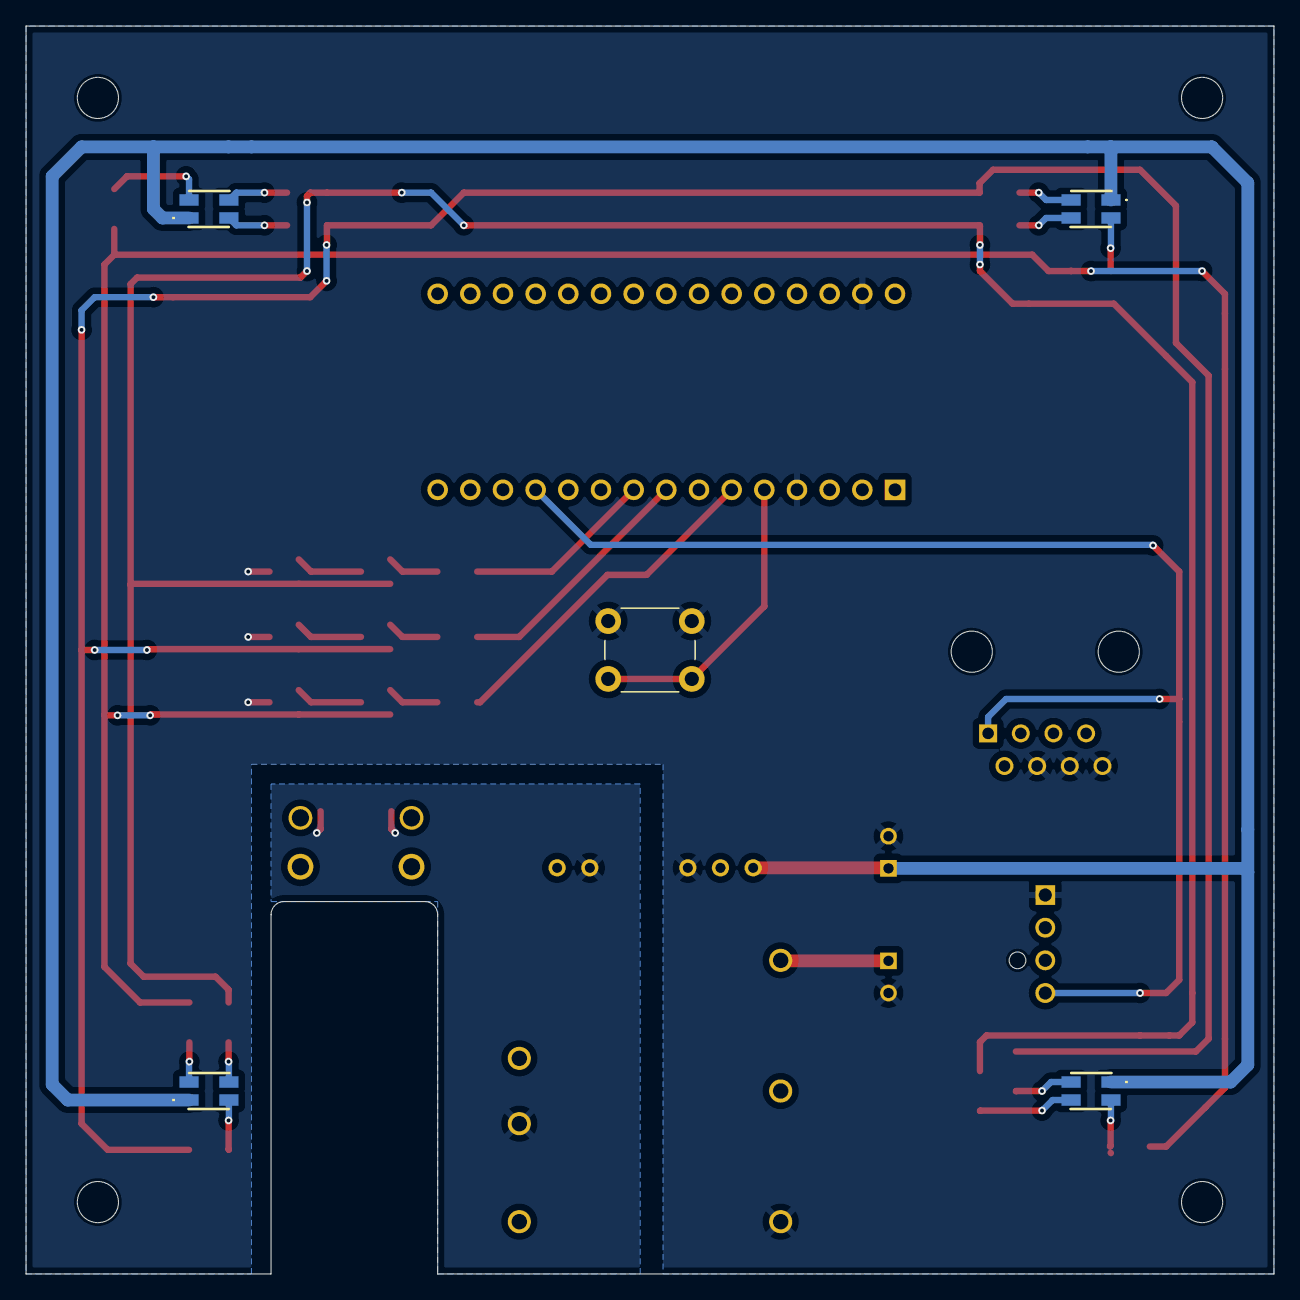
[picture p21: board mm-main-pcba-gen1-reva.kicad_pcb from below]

Board: 2 copper layers, 97.0 x 97.0 mm, 34 parts (5 on the bottom side), 31 nets.

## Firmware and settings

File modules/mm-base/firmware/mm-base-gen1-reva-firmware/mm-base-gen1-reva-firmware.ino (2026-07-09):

/*
  MakaniMotion MM-BASE GEN 1 Rev A Firmware

  Short button press:
    Cycle through PWM stages.

  Long button press:
    Toggle RGB status LEDs on/off.

  RGB LEDs:
    Non-blocking pulse effect during normal operation.
*/

const byte OC1A_PIN = 9;     // PWM output for fan control, D9 / OC1A
const byte BUTTON_PIN = 2;   // Button input, D2, active LOW

const byte RED_PIN = 5;      // RGB LED red channel
const byte GREEN_PIN = 6;    // RGB LED green channel
const byte BLUE_PIN = 3;     // RGB LED blue channel

const word PWM_FREQ_HZ = 25000;
const word TCNT1_TOP = F_CPU / (2 * PWM_FREQ_HZ);

// PWM stages in percent
const byte PWM_STAGES[] = {33, 66, 100};
const byte PWM_STAGE_COUNT = sizeof(PWM_STAGES) / sizeof(PWM_STAGES[0]);

byte currentStage = 0;

// Button handling
const unsigned long DEBOUNCE_DELAY_MS = 40;
const unsigned long LONG_PRESS_MS = 1000;

byte lastButtonReading = HIGH;
byte stableButtonState = HIGH;

unsigned long lastDebounceTime = 0;
unsigned long buttonPressStartTime = 0;

bool longPressHandled = false;

// LED handling
bool ledsEnabled = true;

const unsigned long LED_PULSE_INTERVAL_MS = 15;
const byte LED_PULSE_MIN = 25;
const byte LED_PULSE_MAX = 255;
const byte LED_PULSE_STEP = 2;

unsigned long lastLedPulseUpdate = 0;
byte ledPulseValue = LED_PULSE_MIN;
int ledPulseDirection = 1;

void setup() {
  pinMode(OC1A_PIN, OUTPUT);
  pinMode(BUTTON_PIN, INPUT_PULLUP);

  pinMode(RED_PIN, OUTPUT);
  pinMode(GREEN_PIN, OUTPUT);
  pinMode(BLUE_PIN, OUTPUT);

  setupTimer1ForFanPwm();

  setPwmDuty(PWM_STAGES[currentStage]);
  updateLedPulse();
}

void loop() {
  handleButton();
  updateLedPulse();
}

void setupTimer1ForFanPwm() {
  // Reset Timer1 registers
  TCCR1A = 0;
  TCCR1B = 0;
  TCNT1 = 0;

  // Phase Correct PWM on OC1A, no prescaler
  TCCR1A |= (1 << COM1A1) | (1 << WGM11);
  TCCR1B |= (1 << WGM13) | (1 << CS10);

  // Set TOP value for 25 kHz PWM
  ICR1 = TCNT1_TOP;
}

void handleButton() {
  byte reading = digitalRead(BUTTON_PIN);

  // Debounce input
  if (reading != lastButtonReading) {
    lastDebounceTime = millis();
  }

  if ((millis() - lastDebounceTime) > DEBOUNCE_DELAY_MS) {
    if (reading != stableButtonState) {
      stableButtonState = reading;

      if (stableButtonState == LOW) {
        // Button was pressed
        buttonPressStartTime = millis();
        longPressHandled = false;
      } else {
        // Button was released
        if (!longPressHandled) {
          nextPwmStage();
        }
      }
    }

    // Long press while button is still held
    if (stableButtonState == LOW && !longPressHandled) {
      if ((millis() - buttonPressStartTime) >= LONG_PRESS_MS) {
        toggleLeds();
        longPressHandled = true;
      }
    }
  }

  lastButtonReading = reading;
}

void nextPwmStage() {
  currentStage = (currentStage + 1) % PWM_STAGE_COUNT;
  setPwmDuty(PWM_STAGES[currentStage]);

  // Restart pulse at a defined brightness after changing stage
  ledPulseValue = LED_PULSE_MIN;
  ledPulseDirection = 1;
}

void toggleLeds() {
  ledsEnabled = !ledsEnabled;

  if (!ledsEnabled) {
    setRgbRaw(0, 0, 0);
  } else {
    ledPulseValue = LED_PULSE_MIN;
    ledPulseDirection = 1;
    updateLedPulse();
  }
}

void setPwmDuty(byte duty) {
  OCR1A = (word)(duty * TCNT1_TOP) / 100;
}

void updateLedPulse() {
  if (!ledsEnabled) {
    setRgbRaw(0, 0, 0);
    return;
  }

  if ((millis() - lastLedPulseUpdate) < LED_PULSE_INTERVAL_MS) {
    return;
  }

  lastLedPulseUpdate = millis();

  int nextValue = ledPulseValue + (ledPulseDirection * LED_PULSE_STEP);

  if (nextValue >= LED_PULSE_MAX) {
    nextValue = LED_PULSE_MAX;
    ledPulseDirection = -1;
  } else if (nextValue <= LED_PULSE_MIN) {
    nextValue = LED_PULSE_MIN;
    ledPulseDirection = 1;
  }

  ledPulseValue = (byte)nextValue;

  setStageColorScaled(currentStage, ledPulseValue);
}

void setStageColorScaled(byte stage, byte brightness) {
  byte red = 0;
  byte green = 0;
  byte blue = 0;

  switch (stage) {
    case 0:
      // Stage 1: Blue
      red = 0;
      green = 0;
      blue = 255;
      break;

    case 1:
      // Stage 2: Green
      red = 0;
      green = 255;
      blue = 0;
      break;

    case 2:
      // Stage 3: Cyan
      red = 0;
      green = 255;
      blue = 255;
      break;
  }

  setRgbRaw(
    scaleColor(red, brightness),
    scaleColor(green, brightness),
    scaleColor(blue, brightness)
  );
}

byte scaleColor(byte color, byte brightness) {
  return (byte)((word)color * brightness / 255);
}

void setRgbRaw(byte red, byte green, byte blue) {
  analogWrite(RED_PIN, red);
  analogWrite(GREEN_PIN, green);
  analogWrite(BLUE_PIN, blue);
}

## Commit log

2026-07-08 Initial MM-Fan GEN 1 repository setup
    [mm-air-gen1-reva-bom.xlsx, mm-air-shroud-gen1-reva.stl, mm-base-gen1-enclosure-cover-reva.step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]
2026-07-09 Update images, BOMs and MM-BASE firmware
    [mm-air-gen1-reva-bom.xlsx, mm-base-gen1-reva-bom.xlsx]
2026-07-09 Improve MM-BASE firmware button handling
2026-07-10 Update banner size and add MM-BASE USB parts
    [mm-base-gen1-reva-bom.xlsx]
